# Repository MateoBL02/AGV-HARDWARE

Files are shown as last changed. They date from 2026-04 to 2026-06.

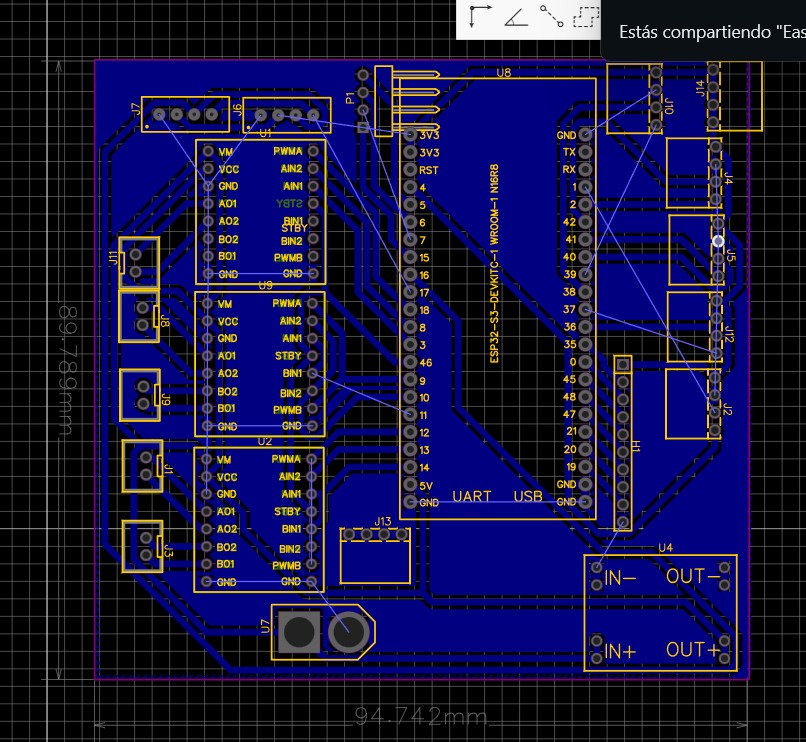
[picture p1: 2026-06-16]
03_PCB_Electronica/esquematico/WhatsApp Image 2026-06-08 at 18.03.01.jpeg

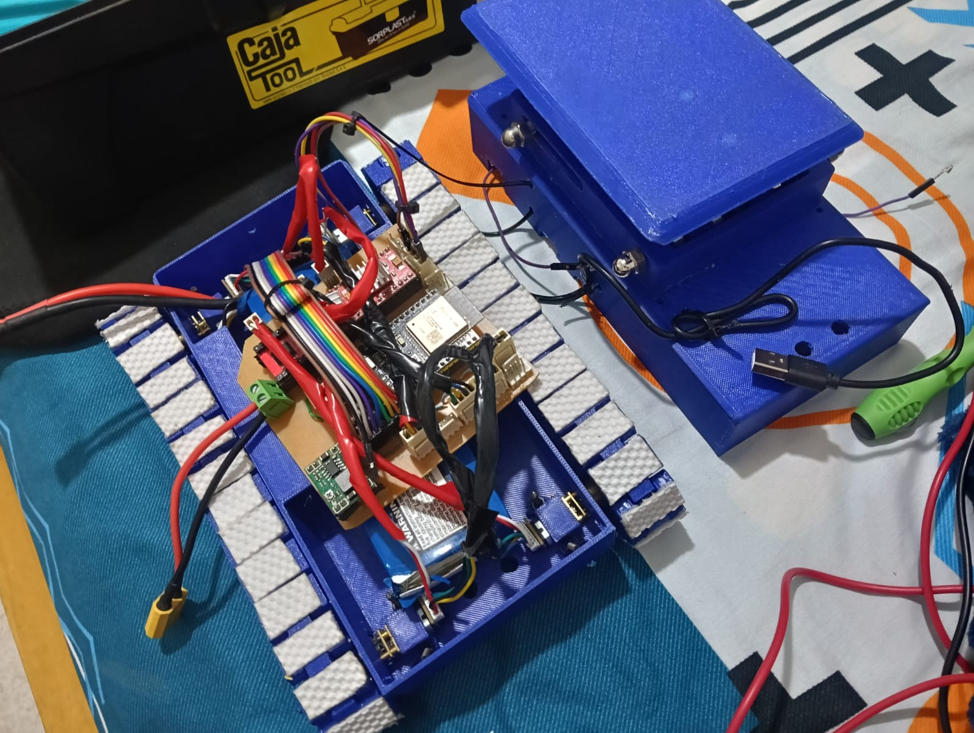
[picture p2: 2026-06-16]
05_Pruebas/fotos/carro2.png

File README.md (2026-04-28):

# AGV Hardware — Grupo 2 | Universidad de Pamplona

**Proyecto:** AS/RS Automatizado  
**Etapa:** Specification / Design  
**Grupo:** G2 — AGV Hardware  
**Integrantes:** Ivan Briceño, Carlos Adame, Andres Tolosa, Mateo Barragan, Cristian Becerra  
**Fecha:** Abril 2026

---

## Descripción del Subsistema

El AGV (Automated Guided Vehicle) implementa una arquitectura de tracción tipo oruga con control diferencial. Cada lado está conformado por dos motores DC N20 con reductor conectados en paralelo mecánico, controlados mediante puentes H TB6612FNG. El seguimiento de trayectoria se realiza con el sensor QTR-8A y la lógica de control corre en un ESP32-S3.

El sistema incluye:
- **Tracción diferencial** con 4 motores N20 (2 por lado)
- **Sistema de elevación** mediante tornillo sin fin accionado por un motor N20 adicional
- **Sensórica:** QTR-8A (seguimiento de línea), TCS34725 (color), encoders Hall magnéticos, final de carrera
- **Control:** ESP32-S3-DevKitC-1 WROOM-1 N16R8
- **Drivers:** 3x TB6612FNG
- **Alimentación:** Batería LiPo 3S (11.1V–12.6V) + regulador MP23070N (→ 5V/3.3V)
- **Comunicación:** WiFi

---

## Estructura del Repositorio

```
g2-agv-hardware/
├── 01_CAD_3D/              # Modelos 3D del AGV completo
│   ├── partes/             # Archivos CAD individuales de cada pieza
│   └── ensambles/          # Ensambles completos del AGV
├── 02_Planos_2D/           # Planos de fabricación con cotas y tolerancias (PDF)
├── 03_PCB_Electronica/     # Diseño eléctrico/electrónico
│   ├── esquematico/        # Esquemático del circuito (EasyEDA / KiCad)
│   └── layout/             # PCB Layout y ruteo
├── 04_BOM/                 # Bill of Materials definitivo
├── 05_Pruebas/             # Documentación de pruebas unitarias
│   ├── registros_escritos/ # Informes y registros escritos
│   ├── fotos/              # Registro fotográfico
│   └── videos/             # Registro en video
└── 06_Documentacion/       # Documentos del proyecto (IBD, Pflichtenheft, etc.)
```

---

## Actividades del Grupo

1. **Diseño 3D definitivo** del AGV completo — CADs de partes para manufactura y ensamble final.
2. **Ruteo PCB y Layout** eléctrico/electrónico de sensores, actuadores y componentes del subsistema.
3. **Pruebas unitarias** a las unidades existentes del AGV con documentación escrita, fotográfica y en video:
   - Sistema de traslación
   - Sistema de recolección de caja
   - Sistemas de detección de objetos
   - Sistema de control general

---

## Entregables

- Rama `g2-agv-hardware` en el repositorio central con archivos y documentos organizados.
- Planos 2D de fabricación con cotas, tolerancias y materiales — rótulo institucional (PDF).
- BOM definitivo con todos los componentes (existentes y nuevos).
- Archivos CAD completos: partes individuales y ensambles.

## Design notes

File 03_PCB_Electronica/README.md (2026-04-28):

# 03 — PCB y Electrónica

Diseño eléctrico y electrónico del AGV: esquemático, ruteo de PCB y layout de conexiones.

## Componentes principales del sistema

| Componente | Función | Especificación |
|---|---|---|
| ESP32-S3-DevKitC-1 WROOM-1 N16R8 | Microcontrolador principal | WiFi, 3.3V, múltiples GPIO/ADC |
| TB6612FNG (x3) | Drivers puente H | Hasta 15V / 1.2A continuo por canal |
| Motor N20 con encoder Hall (x5) | Tracción (x4) + Elevación (x1) | 12VDC, 200 RPM |
| QTR-8A | Sensor seguidor de línea | 8 IR analógicos, 5V |
| TCS34725 | Sensor de color | I2C, 3.3V |
| MP23070N | Regulador buck 12V→5V | Alta eficiencia |
| Final de carrera (FC1) | Límite de elevación | COM/NO/NC |
| Batería LiPo 3S | Alimentación principal | 11.1V–12.6V / conector XT60 |

## Subcarpetas

### `esquematico/`
- Archivo fuente del esquemático (EasyEDA, KiCad, etc.)
- Exportación en PDF del esquemático completo
- Archivo fuente: `Esquematico_Diseño2` (EasyEDA)

### `layout/`
- Archivo de PCB con ruteo completo
- Gerbers para fabricación
- Imagen de la PCB (top y bottom layer)

## Asignación de pines ESP32-S3

| GPIO | Señal |
|---|---|
| IO1 | enc1a |
| IO2 | enc1b |
| IO39 | enc2a |
| IO40 | enc2b |
| IO41 | enc3a |
| IO42 | enc3b |
| IO35 | enc4a |
| IO38 | enc4b |
| IO36 | enc5a |
| IO33 | enc5b |
| IO3 | enc1a (QTR) |
| IO8 | pwmplataforma |
| IO18 | in2plataforma |
| IO3 | in1plataforma |
| IO9 | pwmizquierdo |
| IO10 | in2izquierdo |
| IO11 | in1izquierdo |
| IO12 | pwmderecho |
| IO13 | in2derecho |
| IO14 | in1derecho |
| IO4 | SDASC (TCS34725) |
| IO5 | SCLSC (TCS34725) |
| IO15 | FC1 (final de carrera) |
| IO16 | SCL (I2C general) |
| IO17 | SDA (I2C general) |

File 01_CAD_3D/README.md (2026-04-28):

# 01 — Diseño CAD 3D

Contiene los archivos de diseño tridimensional del AGV completo para manufactura y ensamble final.

## Subcarpetas

### `partes/`
Archivos CAD individuales de cada componente diseñado o adaptado:
- Chasis principal
- Soportes de motores
- Mecanismo de elevación (tornillo sin fin + plataforma)
- Ruedas / orugas
- Soportes de sensores (QTR-8A, TCS34725)
- Soporte de la PCB y electrónica
- Otros elementos estructurales

### `ensambles/`
Ensambles completos del AGV:
- Ensamble general del vehículo
- Subensamble del sistema de tracción
- Subensamble del sistema de elevación

## Formatos aceptados
- `.STEP` / `.STP` — intercambio entre herramientas CAD (preferido)
- `.STL` — para impresión 3D
- `.f3d` — Fusion 360
- `.SLDPRT` / `.SLDASM` — SolidWorks

## Notas
- Todos los archivos deben incluir el nombre del componente y versión en el nombre del archivo.
- Ejemplo: `chasis_principal_v1.step`, `ensamble_general_v2.step`

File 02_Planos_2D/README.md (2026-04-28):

# 02 — Planos de Fabricación 2D

Planos técnicos con cotas, tolerancias y materiales para la fabricación de componentes del AGV.

## Requisitos de cada plano

- Formato: **PDF**
- Escala indicada
- Cotas y tolerancias dimensionales completas
- Material especificado
- **Rótulo institucional** — Universidad de Pamplona
  - Nombre del proyecto: AS/RS Automatizado
  - Grupo: G2 — AGV Hardware
  - Nombre del componente
  - Fecha, revisión y dibujante

## Contenido esperado

| Archivo | Componente |
|---|---|
| `plano_chasis.pdf` | Chasis principal del AGV |
| `plano_plataforma_elevacion.pdf` | Plataforma de elevación de carga |
| `plano_soporte_motores.pdf` | Soporte de motores de tracción |
| `plano_soporte_sensores.pdf` | Soporte del arreglo de sensores QTR-8A |
| `plano_ensamble_general.pdf` | Vista de ensamble general con referencias |

> Agregar planos adicionales según las piezas finales del diseño.

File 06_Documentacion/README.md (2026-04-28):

# 06 — Documentación del Proyecto

Documentos técnicos y de gestión del subsistema AGV Hardware.

## Documentos incluidos

| Archivo | Descripción |
|---|---|
| `IBD_Hardware.pdf` | Internal Block Diagram — arquitectura del hardware del AGV |
| `Especificacion_Tecnica_Pflichtenheft.pdf` | Especificación técnica (Pflichtenheft) — descripción funcional, análisis técnico y BOM preliminar |
| `Esquematico_Diseno2.pdf` | Esquemático eléctrico completo del sistema |

## Información del proyecto

- **Proyecto:** AS/RS Automatizado
- **Grupo:** G2 — AGV Hardware
- **Universidad:** Universidad de Pamplona
- **Integrantes:**
  - Ivan Briceño
  - Carlos Adame
  - Andres Tolosa
  - Mateo Barragan
  - Cristian Becerra

## Resumen técnico

- **Microcontrolador:** ESP32-S3-DevKitC-1 WROOM-1 N16R8
- **Tracción:** 4x Motor N20 12VDC 200RPM con encoder Hall — control diferencial tipo oruga
- **Elevación:** 1x Motor N20 + tornillo sin fin
- **Drivers:** 3x TB6612FNG (izquierdo, derecho, plataforma)
- **Sensores:** QTR-8A (línea), TCS34725 (color), encoders, final de carrera
- **Alimentación:** LiPo 3S → MP23070N (5V) → regulador 3.3V interno ESP32
- **Comunicación:** WiFi (ESP32 integrado)
- **Corriente total estimada:** ~3.4A (operación continua)
- **Autonomía estimada:** ~40 minutos con batería 2500 mAh

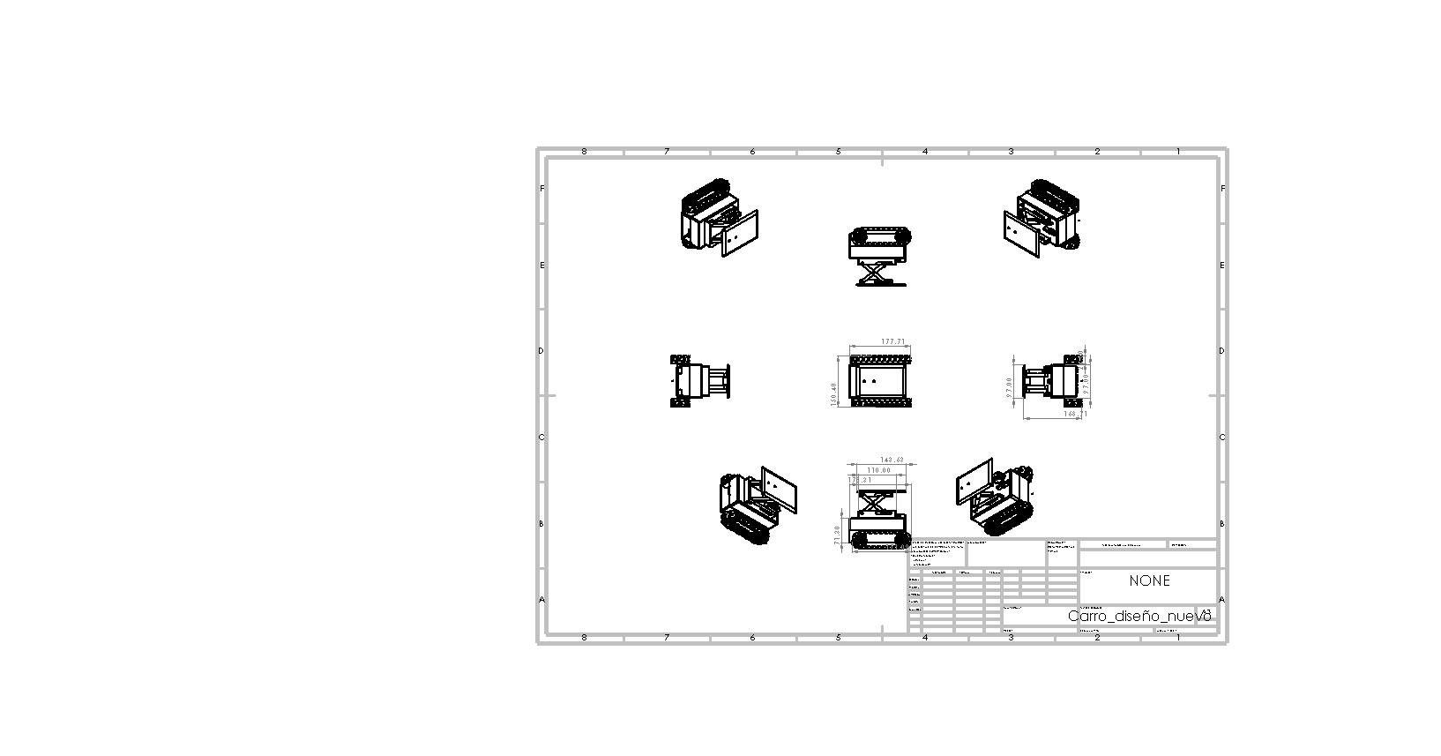
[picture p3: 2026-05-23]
01_CAD_3D/Carro_diseño_nuevo.JPG

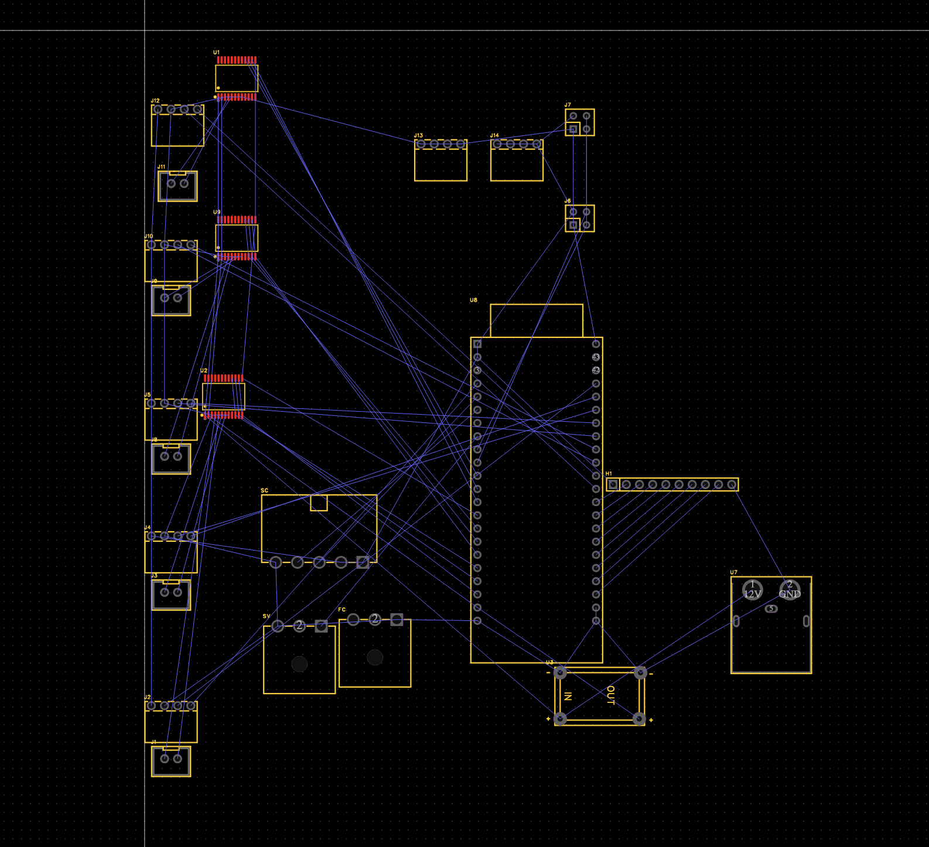
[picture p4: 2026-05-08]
03_PCB_Electronica/layout/pcb 2d.png

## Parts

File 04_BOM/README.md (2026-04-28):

# 04 — BOM (Bill of Materials) Definitivo

Listado completo de materiales y componentes necesarios para la siguiente etapa de fabricación del AGV. Incluye tanto los componentes ya existentes como los nuevos.

## Archivo BOM

El BOM definitivo debe entregarse en formato `.xlsx` o `.pdf` con la siguiente estructura:

| # | Componente | Referencia | Cantidad | Función | Especificación clave | Estado |
|---|---|---|---|---|---|---|
| 1 | Microcontrolador | ESP32-S3-DevKitC-1 WROOM-1 N16R8 | 1 | Control general | WiFi, 3.3V, ADC, PWM | Existente |
| 2 | Driver motor | TB6612FNG | 3 | Control de motores | 15V / 1.2A continuo/canal | Existente |
| 3 | Motor DC con encoder | N20 Hall 12VDC 200RPM | 5 | Tracción (x4) + Elevación (x1) | Torque bloqueado >1.2 kg·cm | Existente |
| 4 | Sensor línea | QTR-8A | 1 | Seguimiento de trayectoria | 8 IR analógico, 5V | Existente |
| 5 | Sensor color | TCS34725 | 1 | Detección de color | I2C, 3.3V | Existente |
| 6 | Regulador voltaje | MP23070N | 1 | 12V → 5V/3.3V | Hasta 3A salida | Existente |
| 7 | Batería | LiPo 3S 2500mAh | 1 | Alimentación principal | 11.1V–12.6V, ~40 min autonomía | Existente |
| 8 | Conector batería | XT60 | 1 | Conexión batería | — | Existente |
| 9 | Final de carrera | Microswitch COM/NO/NC | 1 | Límite elevación | — | Existente |
| 10 | Conectores I2C | Male Header 4 pines | 2 | Expansión I2C | GND/VCC/SCL/SDA | Existente |

> Este BOM es preliminar. Actualizar con cantidades exactas, referencias de proveedor y precios para la entrega final.

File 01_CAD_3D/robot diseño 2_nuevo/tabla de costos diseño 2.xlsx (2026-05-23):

componentes | imagen | descripocion | opcion 1 | costo/und | opcion 2 | costo | opcion 3 und | c | cantidad | costo total 1 | costo total 2 | costo total 3
motor reductor n20 con encoder | #VALUE! | motores para el sistea de traccion | https://www.didacticaselectronicas.com/shop/n20-30-1-500-enc-6v-micro-motorreductor-n20-con-enconder-6v-500rpm-38492 | 26400 | https://articulo.mercadolibre.com.co/MCO-1662090841-motor-con-encoder-codificador-ga12-n20-dc-6v-1500-rpm-_JM | 70000 | https://es.aliexpress.com/item/1005007321501171.html?curPageLogUid=fgtPSaoVT5LE | 15000 | 4 | 105600 | 280000 | 60000
Motor n20 de eje roscado | #VALUE! | motor de eje roscado para plataforma | https://www.amazon.com/-/es/codificador-tornillo-engranaje-aplicaciones-precisas/dp/B0DBPV8XZJ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 | 150000 |  | 150000 |  | 150000 | 1 | 150000 | 150000 | 150000
sensor de linea | #VALUE! | sensor de linea para verificar si esta sobre la lina | https://www.amazon.com/-/es/seguimiento-infrarroja-reflexi%C3%B3n-canales-3-3V-5V/dp/B091BRVBXD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 | 45000 | https://www.amazon.com/-/es/seguimiento-canales-infrarroja-detecci%C3%B3n-detector/dp/B0DZCFY91N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 | 40000 | https://www.julpin.com.co/inicio/seguidor-de-linea-velocista/1128-sensor-seguidor-de-linea-qtr-8a.html | 35000 | 1 | 45000 | 40000 | 35000
sensor de distancia | #VALUE! | sensor de sistanca para obstaculos | https://www.didacticaselectronicas.com/shop/gy-vl53l0xv2-sensor-vl53l0xv2-de-distancia-laser-7533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 | 8000 | https://www.amazon.com/-/es/ALAMSCN-VL53L0X-VL53L0XV2-medici%C3%B3n-distancia/dp/B08V8SKKZ4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 | 13000 | https://articulo.mercadolibre.com.co/MCO-2972474764-modulo-sensor-de-distancia-por-laser-940nm-i2c-hasta-2m-_JM | 15000 | 2 | 16000 | 26000 | 30000
berias | #VALUE! | para poder | https://www.mercadolibre.com.co/bateria-21700-5000-mah-reales-37v/up/MCOU3254361602 | 27000 | https://www.mercadolibre.com.co/1-x-bateria-de-litio-panasonic-21700-5000mah-envio-gratis-/p/MCO2042744525 | 50000 | https://www.julpin.com.co/inicio/pilas-y-baterias/1800-bateria-de-litio-de-37v-y-4000ma.html | 38000 | 0 | 0 | 0 | 0
puente h | #VALUE! | puente h para plataform y traccion | https://www.amazon.com/-/es/TB6612FNG-controlador-TB6612-microcontrolador-reemplazar/dp/B0F7RGWQ8B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 | 11000 | https://www.didacticaselectronicas.com/shop/tb6612fng-driver-dual-motor-dc-tb6612fng-10322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 | 10000 | https://www.mercadolibre.com.co/driver-tb6612-doble-puente-h-15v-max-12a-robotica-l298-sgk/p/MCO2040552181 | 10900 | 3 | 33000 | 30000 | 32700
final de carrera | #VALUE! | para poder saber cuando llega la plataforma al inicio | https://www.julpin.com.co/inicio/control-de-impresoras-3d/1278-final-de-carrera-ramps-14.html | 8000 | https://www.mercadolibre.com.co/endstop--final-de-carrera-para-impresora-3d--cnc/up/MCOU2427669013 | 10000 | https://www.mercadolibre.com.co/endstop--final-de-carrera-para-impresora-3d-reprap-ramps/up/MCOU2427664477 | 6000 | 2 | 16000 | 20000 | 12000
esp 32 dev quit c1 | #VALUE! | control del veiculo | https://articulo.mercadolibre.com.co/MCO-1701476567-placa-esp32-s3-tipo-c-_JM | 55000 | https://www.mercadolibre.com.co/esp32-s3-devkitc-1-n16r8-240mhz-wifi-24ghz-bt-ble-5-mesh-ia/up/MCOU2415072850 | 39800 | https://www.mercadolibre.com.co/tarjeta-esp32s3-esp32-s3-n16r8-wifi-bluetooth/up/MCOU2402821401 | 40000 | 0 | 0 | 0 | 0
 |  |  |  |  |  |  |  |  | total | 365600 | 546000 | 319700

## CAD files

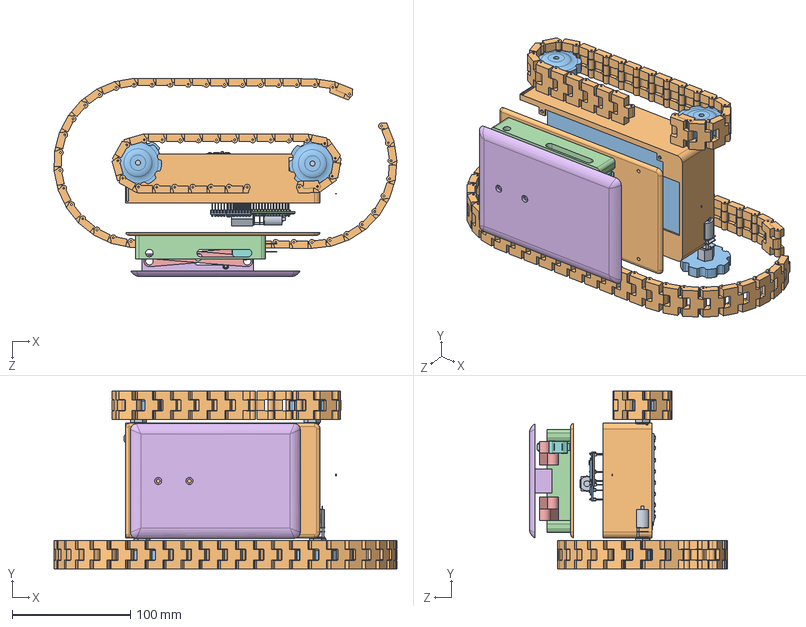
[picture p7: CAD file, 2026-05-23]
01_CAD_3D/Carro_diseño_nuevo.SLDASM
290.2 x 150.4 x 167.9 mm
N20 Motor x 5
Pieza7^robot pqueño final1 chasis
TB6612FNG_Lower Pins.step x 3
pcb Geometry.step
TEXT.step
SW Geometry.step x 2
Botton.step x 2
sold.step x 2
cu.step x 2
Soket Geometry.step
Frame.step
cu2.step
pin.step
Transistor Geometry.step x 2
body.step x 2
pin2.step x 2
cu3.step x 2
R Geometry.step x 16
pin3.step x 16
cu4.step x 16
C Geometry.step x 7
Pin-sold.step x 7
cu5.step x 7
IC1 Geometry.step
sold2.step
Body2.step
CPU Geometry.step
Sold3.step
IC2 Geometry.step
pin4.step
weld.step
D Geometry.step
Pin-sold2.step
cu7.step
labl.step
LED Geometry.step
body3.step
pin5.step
cu8.step
D1 Geometry.step
Pin-sold3.step
cu9.step
D2 Geometry.step
Pin-sold4.step
cu10.step
labl2.step
pin6.step x 38
SW3dPS-0603_SMD_Resistor.step
QTR-8A
oruga pequeña x 72
piñon oruga pequeña x 4
Pieza10^robot pqueño base mecanismo de tigera
Pieza11^Carro_diseño_nuevo x 4
Pieza12^Carro_diseño_nuevo
tcs34725_rgb_sensor.igs
FINAL DE CARRERA.step
Soporte N20x2.step x 2
Pieza Chasis tapa
Pieza13

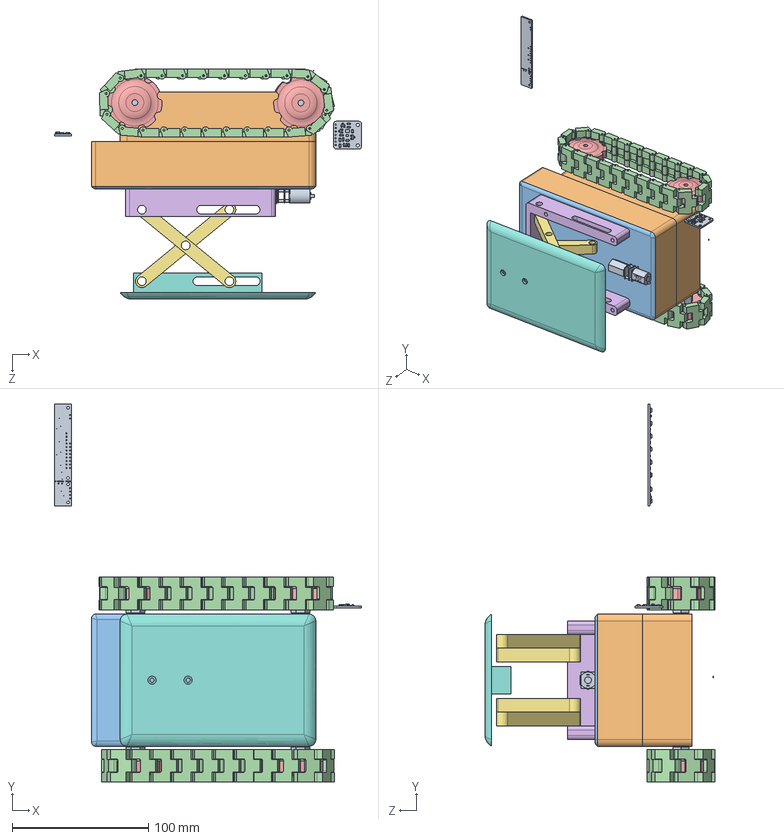
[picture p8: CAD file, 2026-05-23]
01_CAD_3D/robot diseño 2_nuevo/robot pqueño.SLDASM
225.4 x 277.4 x 169.1 mm
N20 Motor x 5
Pieza7^robot pqueño final chasis
TB6612FNG_Lower Pins.step x 3
pcb Geometry.step
TEXT.step
SW Geometry.step x 2
Botton.step x 2
sold.step x 2
cu.step x 2
Soket Geometry.step
Frame.step
cu2.step
pin.step
Transistor Geometry.step x 2
body.step x 2
pin2.step x 2
cu3.step x 2
R Geometry.step x 16
pin3.step x 16
cu4.step x 16
C Geometry.step x 7
Pin-sold.step x 7
cu5.step x 7
IC1 Geometry.step
sold2.step
Body2.step
CPU Geometry.step
Sold3.step
IC2 Geometry.step
pin4.step
weld.step
D Geometry.step
Pin-sold2.step
cu7.step
labl.step
LED Geometry.step
body3.step
pin5.step
cu8.step
D1 Geometry.step
Pin-sold3.step
cu9.step
D2 Geometry.step
Pin-sold4.step
cu10.step
labl2.step
pin6.step x 38
SW3dPS-0603_SMD_Resistor.step
QTR-8A
Pieza8^robot pqueño
Pieza9^robot pqueño
oruga pequeña x 48
piñon oruga pequeña x 4
Pieza10^robot pqueño base mecanismo de tigera
Pieza11^robot pqueño x 4
Pieza12^robot pqueño
tcs34725_rgb_sensor.igs

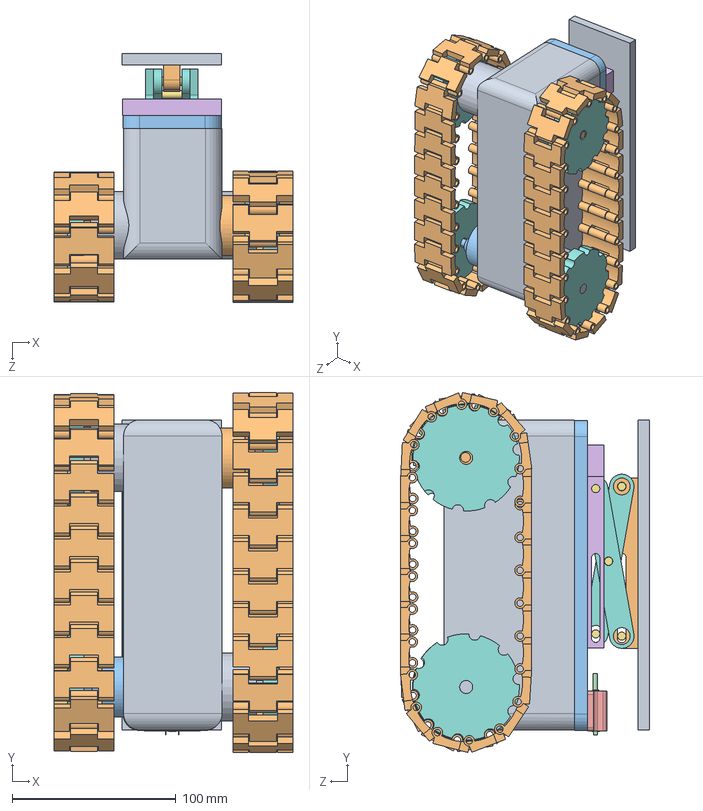
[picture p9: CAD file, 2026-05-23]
01_CAD_3D/robot diseño 2_nuevo/Ensamblaje2 prueba componentes.SLDASM
145.9 x 220.0 x 152.1 mm
bateria
motor traccion
Pieza1
pcb Geometry.step
TEXT.step
SW Geometry.step x 2
Botton.step x 2
sold.step x 2
cu.step x 2
Soket Geometry.step
Frame.step
cu2.step
pin.step
Transistor Geometry.step x 2
body.step x 2
pin2.step x 2
cu3.step x 2
R Geometry.step x 16
pin3.step x 16
cu4.step x 16
C Geometry.step x 7
Pin-sold.step x 7
cu5.step x 7
IC1 Geometry.step
sold2.step
Body2.step
CPU Geometry.step
Sold3.step
IC2 Geometry.step
pin4.step
weld.step
D Geometry.step
Pin-sold2.step
cu7.step
labl.step
LED Geometry.step
body3.step
pin5.step
cu8.step
D1 Geometry.step
Pin-sold3.step
cu9.step
D2 Geometry.step
Pin-sold4.step
cu10.step
labl2.step
pin6.step x 38
base orufa 1 x 4
Pieza47^Ensamblaje2 prueba componentes
base orga 2 x 48
Pieza48^Ensamblaje2 prueba componentes
N20 Motor
Pieza49^Ensamblaje2 prueba componentes
Pieza50^Ensamblaje2 prueba componentes
Pieza51^Ensamblaje2 prueba componentes x 5
Pieza52^Ensamblaje2 prueba componentes x 4
Pieza53^Ensamblaje2 prueba componentes
Pieza54^Ensamblaje2 prueba componentes

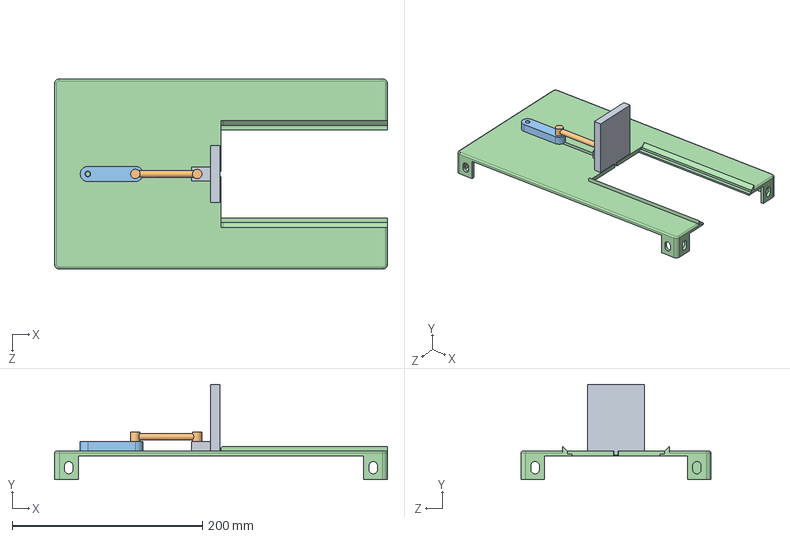
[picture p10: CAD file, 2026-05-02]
01_CAD_3D/robot diseño 2_nuevo/descarga y carga plataforma/Diseño2/EnsamblePlataforma.SLDASM
350.0 x 100.0 x 200.0 mm
Piezaempuje
Viela
Manivela
BasePlataforma

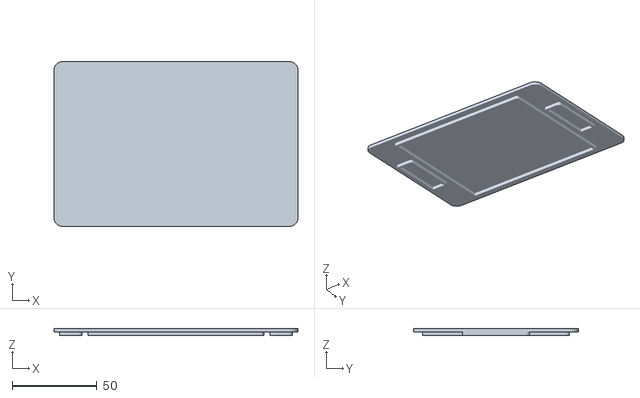
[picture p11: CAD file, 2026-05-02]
01_CAD_3D/robot diseño 2_nuevo/Pieza1^Ensamblaje1 tapa.STL
143.6 x 97.0 x 4.00

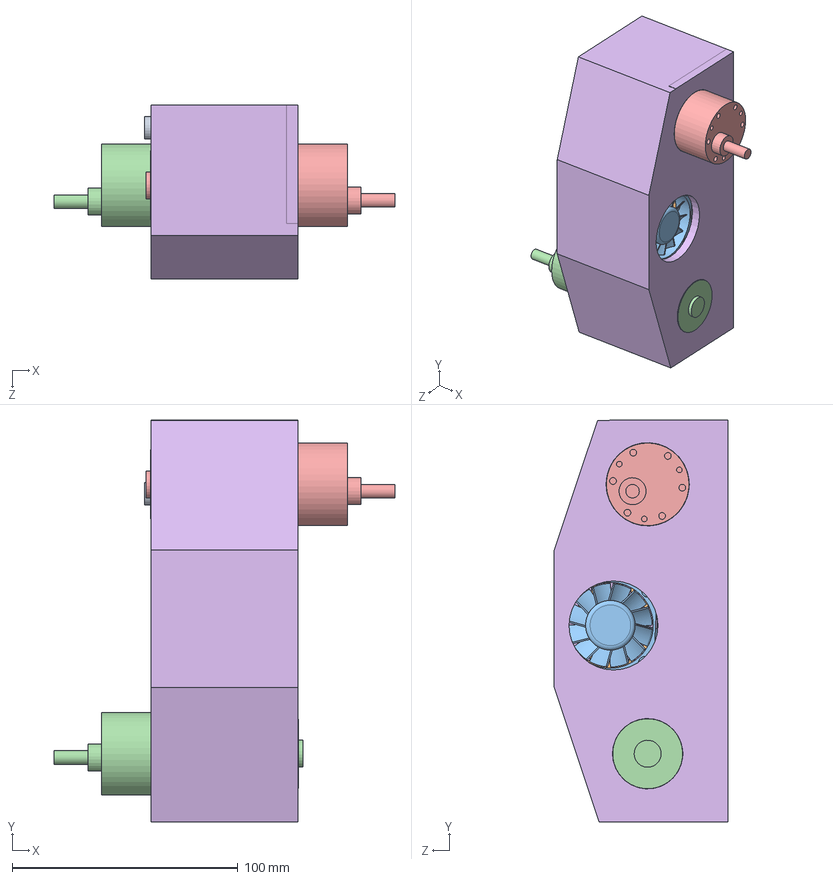
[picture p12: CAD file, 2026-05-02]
01_CAD_3D/robot diseño 2_nuevo/Ensamblaje chasis.SLDASM
151.0 x 178.2 x 76.9 mm
BTS7960 43A HIGH POWER H BRIDGE MODULE x 2
fan_40x40x10
motor traccion
Pieza1
Pieza1^Ensamblaje chasis

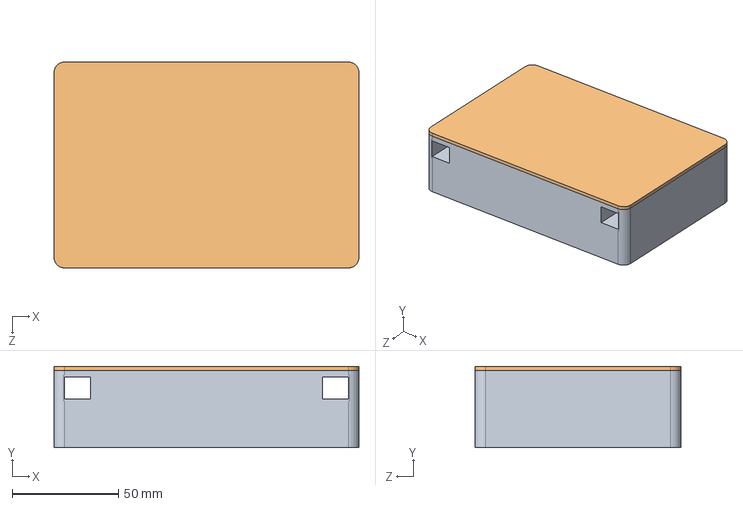
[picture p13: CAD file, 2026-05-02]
01_CAD_3D/robot diseño 2_nuevo/Ensamblaje1 tapa.SLDASM
143.6 x 38.3 x 97.0 mm
Copia de Pieza7^Ensamblaje1 tapa
Pieza1^Ensamblaje1 tapa

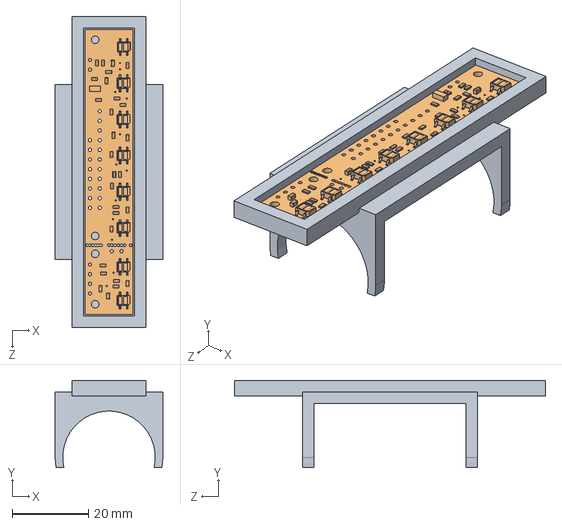
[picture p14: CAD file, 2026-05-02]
01_CAD_3D/robot diseño 2_nuevo/Ensamblaje1.SLDASM
28.3 x 23.0 x 81.7 mm
base qtr 2
QTR-8A

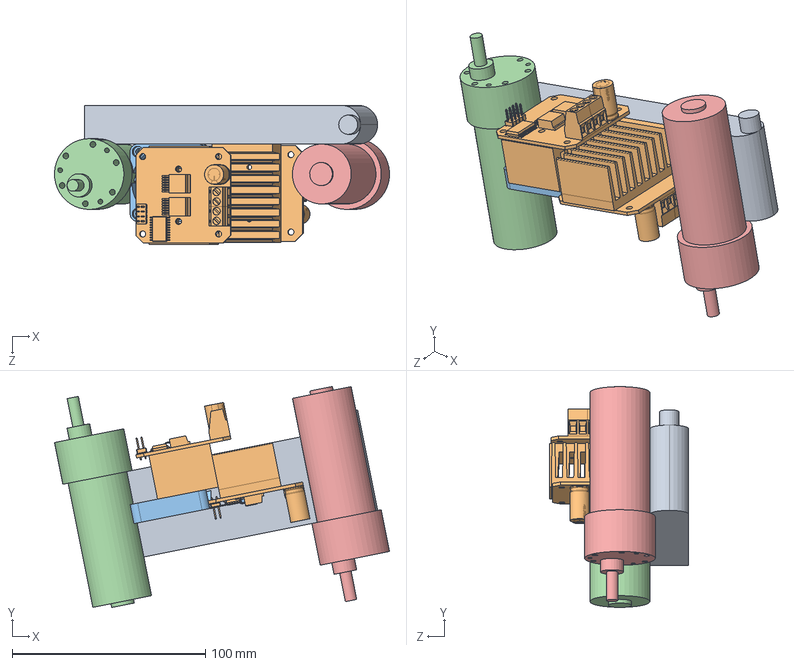
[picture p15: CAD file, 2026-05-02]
01_CAD_3D/robot diseño 2_nuevo/Ensamblaje prueva componenetes.SLDASM
173.2 x 114.3 x 72.0 mm
bateria
BTS7960 43A HIGH POWER H BRIDGE MODULE x 2
fan_40x40x10
motor traccion
Pieza1

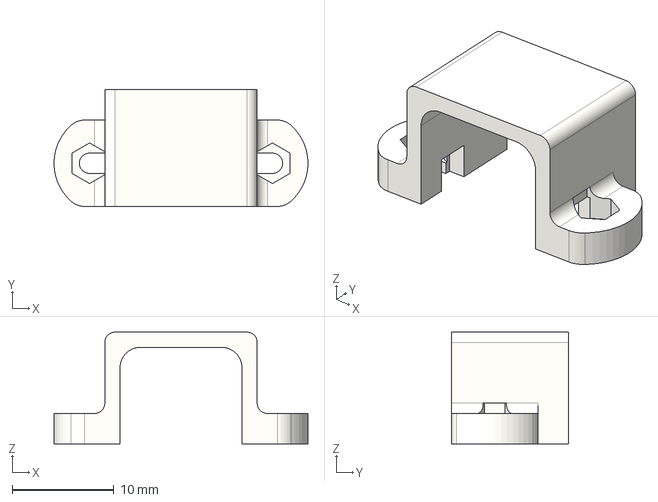
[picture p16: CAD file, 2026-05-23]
01_CAD_3D/Archivos completos/Soporte N20x2.step
25.0 x 11.5 x 11.0 mm

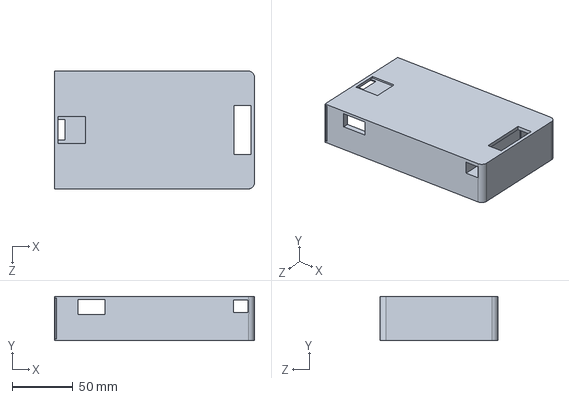
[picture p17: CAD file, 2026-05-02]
01_CAD_3D/partes/Pieza7^robot pqueño final1 chasis.SLDPRT
164.6 x 36.3 x 97.0 mm

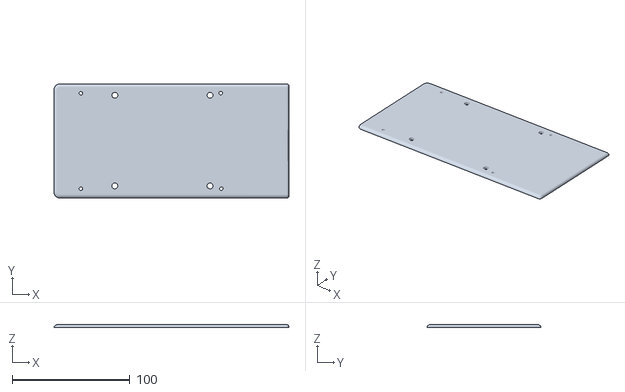
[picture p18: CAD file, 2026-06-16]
01_CAD_3D/Piezas imprimir/Ultimo Chazis_3.STL
199.6 x 97.0 x 2.50

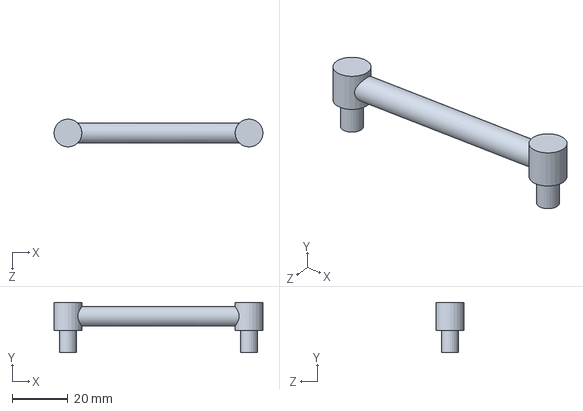
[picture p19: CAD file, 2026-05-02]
01_CAD_3D/robot diseño 2_nuevo/descarga y carga plataforma/Diseño2/Viela.SLDPRT
75.0 x 18.0 x 10.0 mm

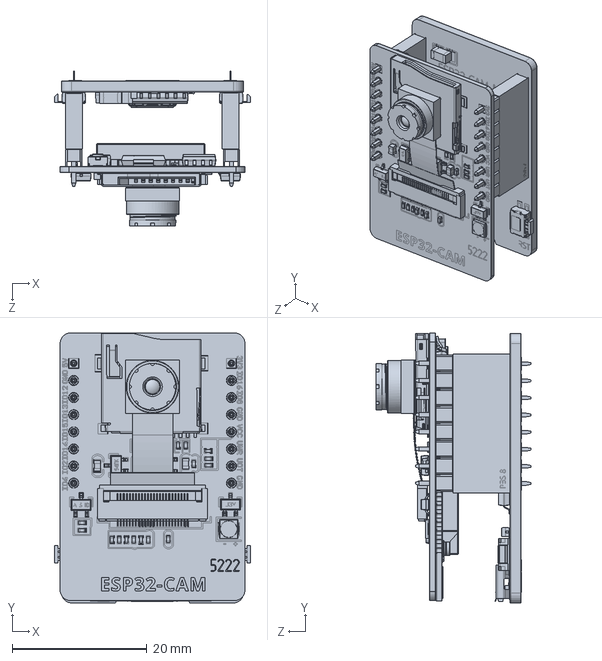
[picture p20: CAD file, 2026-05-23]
01_CAD_3D/robot diseño 2_nuevo/ESP32-CAM-ESP32CAM+MB.SLDPRT
29.1 x 40.1 x 23.0 mm

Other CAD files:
01_CAD_3D/robot diseño 2_nuevo/orugas/piñon oruga pequeña.SLDPRT
01_CAD_3D/robot diseño 2_nuevo/prueva oruga/base orufa 1.SLDPRT
01_CAD_3D/Pieza8^Carro_diseño_nuevo.SLDPRT
01_CAD_3D/Piezas imprimir/Ultimo Chazis_2.STL
01_CAD_3D/Bracket.SLDPRT
01_CAD_3D/Pieza 2 chasis.SLDPRT
01_CAD_3D/Pieza Chasis tapa.SLDPRT
01_CAD_3D/Pieza13.SLDPRT
01_CAD_3D/Piezas imprimir/Carro Diseño Meca2.3mf
01_CAD_3D/Piezas imprimir/Impresion_10_Pieza10^robot pqueño base mecanismo de tigera.STL
01_CAD_3D/Piezas imprimir/Impresion_11_oruga pequeña.STL
01_CAD_3D/Piezas imprimir/Impresion_12_piñon oruga pequeña.STL
01_CAD_3D/Piezas imprimir/Impresion_13_oruga pequeña.STL
01_CAD_3D/Piezas imprimir/Impresion_7_Pieza11^Carro_diseño_nuevo.STL
01_CAD_3D/Piezas imprimir/Impresion_8_Pieza11^Carro_diseño_nuevo.STL
01_CAD_3D/Piezas imprimir/Impresion_9_Pieza11^Carro_diseño_nuevo.STL
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

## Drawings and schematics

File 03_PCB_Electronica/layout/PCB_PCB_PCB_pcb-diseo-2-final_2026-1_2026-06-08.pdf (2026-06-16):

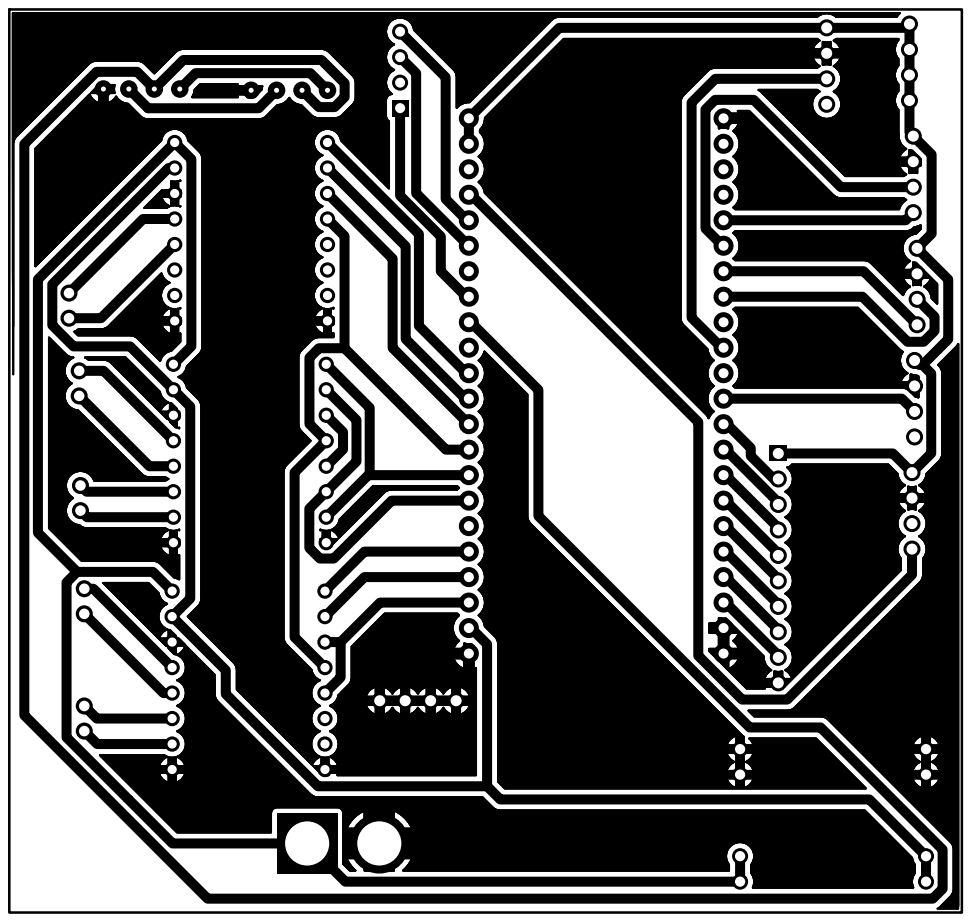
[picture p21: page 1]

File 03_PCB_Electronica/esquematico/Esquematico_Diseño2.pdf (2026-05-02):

J101 1 2 2 3 3 4 4

J121 1 2 2 3 3 4 4

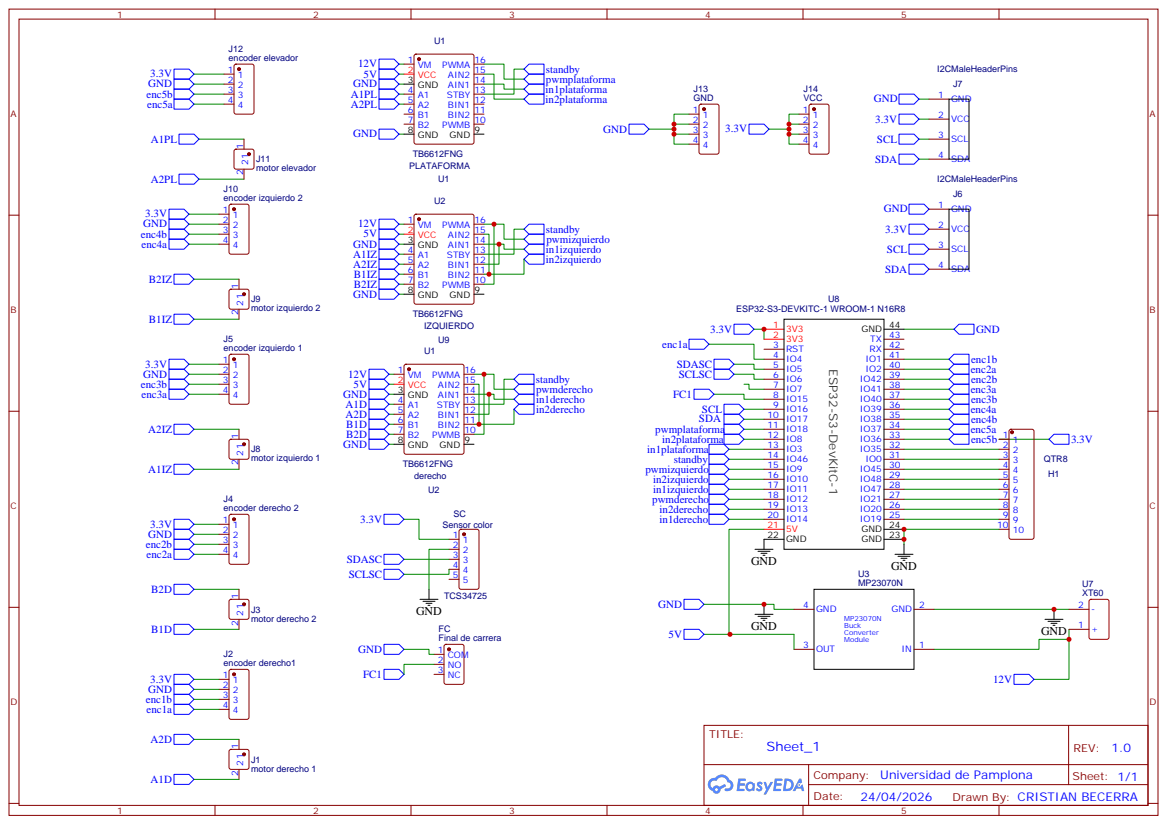
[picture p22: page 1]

Company: Universidad de Pamplona

Drawn By: CRISTIAN BECERRA

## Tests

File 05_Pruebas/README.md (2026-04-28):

# 05 — Pruebas Unitarias

Documentación de las pruebas realizadas a las unidades existentes del AGV. Incluye registros escritos, fotográficos y de video.

## Sistemas a probar

| Sistema | Descripción |
|---|---|
| Sistema de traslación | Prueba de movimiento recto, giro, velocidad y seguimiento de línea |
| Sistema de elevación | Prueba de subida/bajada de plataforma, final de carrera, carga máxima |
| Detección de objetos | Prueba del sensor de color TCS34725 y sensor QTR-8A |
| Sistema de control general | Prueba de comunicación WiFi, latencia, respuesta PWM |

## Estructura de cada registro de prueba

Cada prueba debe documentarse con:

1. **Nombre de la prueba**
2. **Fecha y responsable**
3. **Objetivo**
4. **Procedimiento paso a paso**
5. **Resultados obtenidos** (valores medidos, comportamiento observado)
6. **Criterio de aceptación / fallo**
7. **Conclusión**
8. **Evidencia:** fotos y video referenciados

## Subcarpetas

### `registros_escritos/`
Informes en PDF o DOCX de cada prueba realizada.
- Ejemplo: `prueba_traccion_01.pdf`, `prueba_elevacion_01.pdf`

### `fotos/`
Fotos organizadas por sistema y fecha.
- Ejemplo: `traccion_prueba1_01.jpg`

### `videos/`
Videos de las pruebas. Pueden ser enlaces a Drive o archivos directos.
- Ejemplo: `prueba_seguimiento_linea_v1.mp4`
- O un archivo `links_videos.md` con los enlaces de YouTube/Drive.

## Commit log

2026-04-28 feat: estructura inicial rama g2-agv-hardware
    Se crea la estructura de carpetas y documentación base para el grupo
    G2 AGV Hardware del proyecto AS/RS Automatizado (Universidad de Pamplona).
    Incluye:
    - 01_CAD_3D: carpetas para partes y ensambles del AGV
    - 02_Planos_2D: planos de fabricación con cotas y tolerancias
    - 03_PCB_Electronica: esquemático y layout PCB (TB6612FNG, ESP32-S3, QTR-8A)
    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
2026-05-23 feat: agregar modelos 3D Carro Diseño meca 2
    Añade ensambles, piezas SLDPRT, archivos STL para impresión 3D,
    soporte N20, y subcarpeta robot diseño 2_nuevo con componentes
    electrónicos y mecanismo de tijera/orugas.
    [BT7960B.SLDPRT, BTS7960 43A HIGH POWER H BRIDGE MODULE.SLDPRT, BasePlataforma.SLDPRT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]
2026-06-07 feat: actualizar archivos PCB diseño 2 final
    Reemplaza SCH_EsquematicoCorregido_Final.json por los archivos
    actualizados: esquemático y layout PCB del diseño final
    (ESP32-S3, TB6612FNG x3, encoders, motores, buck converter MP23070N).
2026-06-16 chore: reorganizar repositorio y limpiar archivos duplicados
    - Elimina 17 STL sueltos en la raíz (duplicados de 01_CAD_3D/Piezas imprimir)
    - Elimina 13 CAD duplicados por normalización Unicode (ya presentes en
    01_CAD_3D/robot diseño 2_nuevo) para reducir redundancia
    - Conserva PCB diseño 2 final: agrega esquemático en PDF (Esquematico_Diseño2.pdf)
    junto a los JSON de esquemático y layout y la vista 2D
    - Agrega .gitignore (excluye .zip/.rar/backups >100MB y basura de SO)
    [Impresion_10_Pieza10^robot pqueño base mecanismo de tigera.STL, Impresion_11_oruga pequeña.STL, Impresion_12_piñon oruga pequeña.STL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]
2026-06-16 chore: eliminar últimos 3 STL duplicados de la raíz
    Ya presentes en 01_CAD_3D/Piezas imprimir/. La raíz queda solo con
    las carpetas 01-06 y el README.
    [Imprimir _4_Pieza Chasis tapa.STL, Imprimir_Pieza 2 chasis.STL, Soporte N20.STL]
